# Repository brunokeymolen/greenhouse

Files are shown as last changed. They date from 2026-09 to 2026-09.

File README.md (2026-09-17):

# Greenhouse ESP8266 Relay Controller

Firmware for an ESP-01S relay carrier that ventilates a greenhouse: it reads a
DHT22 and switches a fan - or in winter a lamp or heater - through the on-board
relay.

<p>
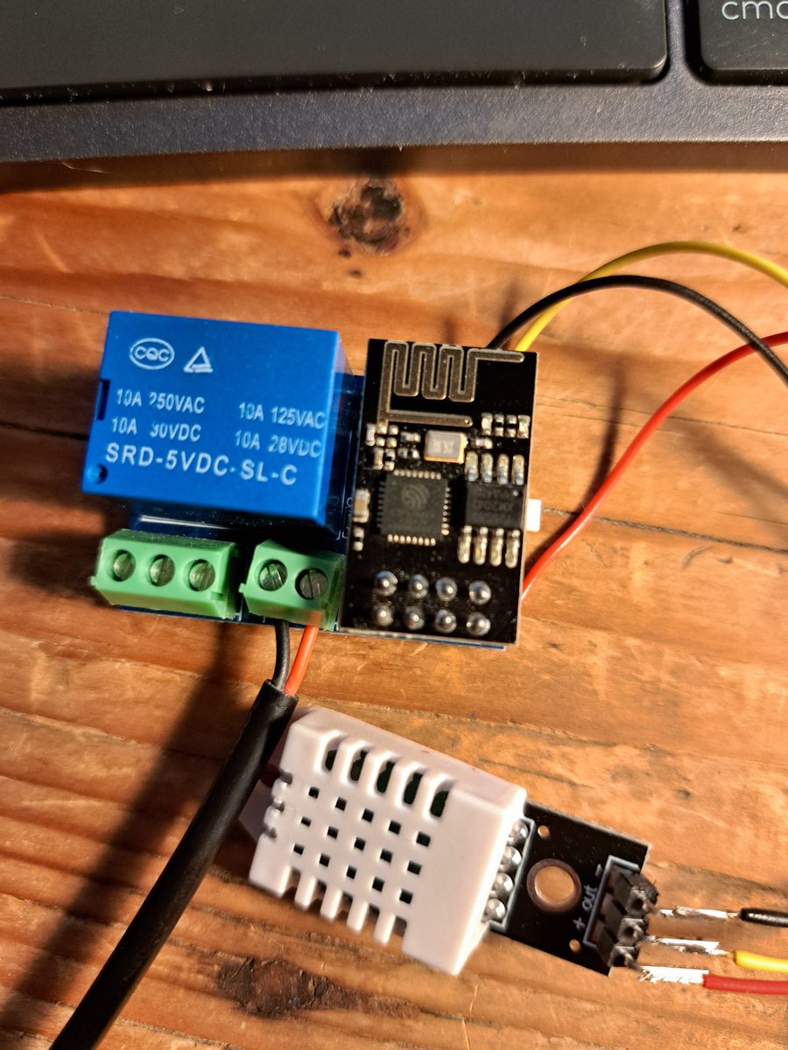
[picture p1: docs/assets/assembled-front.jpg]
ESP-01S module plugged into the relay carrier, with the DHT22 sensor wired to it

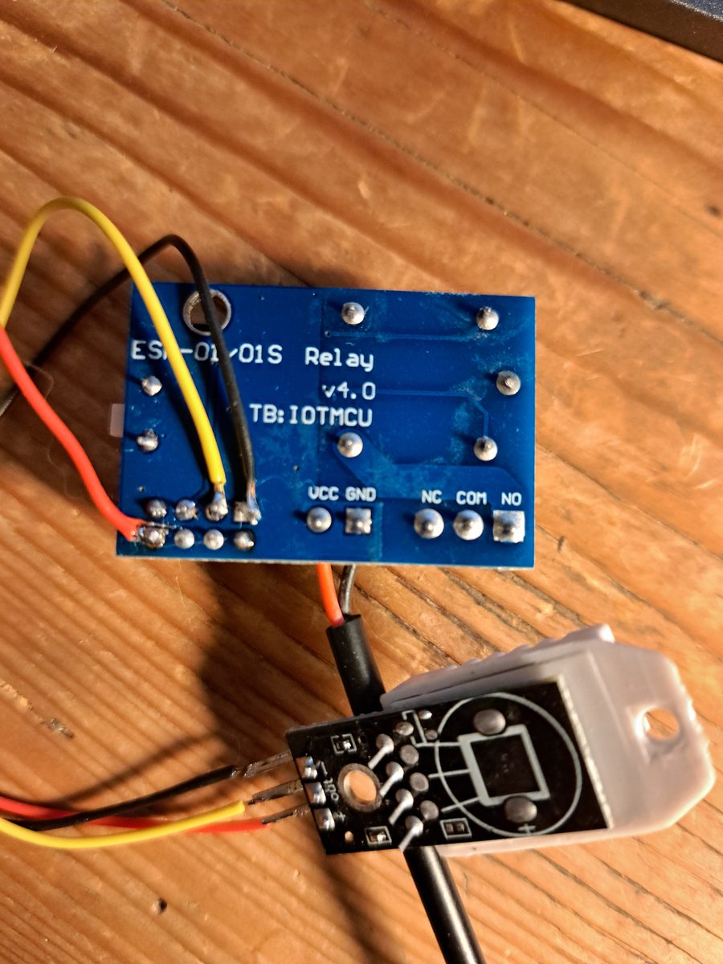
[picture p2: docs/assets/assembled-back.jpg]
Underside of the carrier, showing the ESP-01/01S Relay v4.0 silkscreen and the VCC, GND, NC, COM and NO pads

</p>

**Hardware this is built and tested on**

| Part | What it is |
| --- | --- |
| MCU module | **ESP-01S** - an ESP8266EX with 1 MB flash on the black 8-pin PCB. The build targets 1 MB (`CONFIG_ESPTOOLPY_FLASHSIZE="1MB"`), and the application alone is over 530 kB, so the blue 512 kB ESP-01 will not hold it. |
| Carrier | **ESP-01/01S Relay v4.0**, marked `TB:IOTMCU` on the underside |
| Relay | SRD-05VDC-SL-C, rated 10 A at 250 V AC |
| Sensor | DHT22 / AM2302 (a DHT11 also works; `make menuconfig`) |

Current state: milestones 1-7. The firmware reads a DHT22, runs the fan control
state machine, drives the relay, serves a status and settings page from its own
Wi-Fi access point, and persists its configuration in NVS.

Relay polarity and the GPIO it uses are unconfirmed on real hardware - see
"Bring-up" below before connecting a load.

## Build

Build the toolchain image once, **from the repository root**:

```sh
docker build -t greenhouse-esp8266-idf -f docker/esp8266.Dockerfile .
```

Then build the firmware:

```sh
docker/run.sh make defconfig    # first time only, creates sdkconfig
docker/run.sh make -j
```

`docker/run.sh` mounts this directory into the container, runs as your own user
so build output is not root-owned, sources the SDK environment and passes
`/dev/ttyUSB0` through when it exists.

## Flash and monitor

Put the ESP-01S in the flashing harness, hold `FLASH`, tap `RESET`, then:

```sh
docker/run.sh make -j flash
docker/run.sh make monitor      # exit with Ctrl-]
```

Use `ESPPORT=/dev/ttyUSB1 docker/run.sh ...` for a different serial device. If
opening the port is denied, add yourself to the `dialout` group on the host.

Expected output at 115200 baud:

```text
I (xx) greenhouse: greenhouse controller starting, sdk v3.4
I (xx) sensor: polling DHT22 on GPIO2 every 5 s
I (xx) wifi: SSID Greenhouse-A1B2 up, browse to 192.168.4.1
I (xx) web: http server listening on port 80
I (xx) sensor: 22 C, 47 %RH
```

The ESP8266 ROM bootloader prints its first lines at 74880 baud, so those will
look like garbage in a 115200 terminal. That is normal.

## Using it

Join the `Greenhouse-XXXX` Wi-Fi network (factory password `greenhouse`, change
it with `docker/run.sh make menuconfig`) and open <http://192.168.4.1>. The page
polls `/api/status` every two seconds.

| Path | Method | Purpose |
| --- | --- | --- |
| `/` | GET | Status and settings page |
| `/api/status` | GET | Reading, sensor health, device stats |
| `/api/config` | GET | Current configuration |
| `/api/config` | POST | Validate and save configuration |
| `/api/scan` | GET | Nearby networks, strongest first; blocks ~2 s |
| `/api/history` | GET | Samples for the chart; `?days=1..7` trims the range |
| `/api/relay/test` | POST | Energise the relay briefly; `?seconds=1..5` |
| `/api/reboot` | POST | Restart the controller |

```sh
curl http://192.168.4.1/api/status
```

```json
{"ssid":"Greenhouse-A1B2","valid":true,"stale":false,"temperature_c":22,
 "humidity_pct":47,"age_s":3,"reads_ok":120,"reads_failed":2,
 "last_error":"ok","clients":1,"uptime_s":610,"free_heap":31240}
```

Settings are edited on the page or posted directly. A POST updates only the
fields it names, and is rejected as a whole if any value is out of range — no
partial writes, and out-of-range values are refused rather than silently clamped:

```sh
curl -X POST http://192.168.4.1/api/config \
  -H 'Content-Type: application/json' \
  -d '{"temp_threshold_c":28,"start_delay_s":90}'
```

```json
{"saved":true}
```

| Setting | Default | Bounds |
| --- | ---: | ---: |
| `temp_threshold_c` | 30 | 0-50 |
| `humidity_threshold_pct` | 80 | 20-95 |
| `start_delay_s` | 120 | 0-3600 |
| `max_fan_duration_s` | 900 | 30-7200 |
| `grace_period_s` | 300 | 0-7200 |
| `sensor_poll_interval_s` | 5 | 2-60 |
| `fan_mode` | 1 (auto) | 0 off / 1 auto / 2 on |
| `trigger_direction` | 0 (above) | 0 above / 1 below thresholds |
| `device_name` | `"Fan"` | 1-23 bytes |
| `ap_ssid` | `""` (derive from MAC) | 0-32 bytes |
| `wifi_mode` | 0 (own access point) | 0 access point / 1 join a network |
| `ap_password` | `greenhouse` | 8-63 bytes, or empty for an open network |
| `sta_ssid` | `""` | 0-32 bytes, required when `wifi_mode` is 1 |
| `sta_password` | `""` | 8-63 bytes, or empty for an open network |
| `temp_enabled` | true | bool |
| `humidity_enabled` | true | bool |
| `relay_active_low` | false | bool |

Times are entered in minutes on the page; the API uses seconds throughout.

Both passwords are write-only over the API: `GET /api/config` reports
`ap_password_set` and `sta_password_set` rather than the values, and a `POST`
that carries an empty password leaves the stored one alone.

Settings persist across reboots in NVS. A stored config that is corrupt, written
by a different config version, or out of bounds is discarded and the defaults are
rewritten, so a bad value can never reach the controller. A config written by
version 1 or 3 of the layout is migrated in place instead, keeping the settings
it did have.

Occasional entries in `reads_failed` are normal for a DHT sensor. A rising
`reads_failed` with `valid:false` means wiring — check the pull-up first.

### Power supply

Power the board from a real 5 V supply, not from a computer's USB port and not
from the 5 V of a USB-serial adapter. An ESP8266 draws ~300 mA peaks while
transmitting; a serial adapter's rail sags under that and starves the 3.3 V
regulator into dropout.

It does not fail in any way that looks like a power problem. It shows up as
humidity readings alternating between the true value and roughly double it, while
temperature looks fine. Worse supply adds temperature excursions, then read
timeouts, then all-zero frames.

Fit the decoupling capacitors as well - 10 uF at the regulator output for loop
stability, and 220-470 uF plus 100 nF at the ESP-01's own VCC/GND pins. Both were
necessary; neither was sufficient.

## Sensor

A DHT22/AM2302 is fitted by default; select `DHT11` in `menuconfig` if that is
what is connected. Both use the same single wire and the same driver - they
differ in the host start pulse (about 1 ms versus 18 ms) and in how the 40
payload bits are encoded.

The DHT22 is the better part for this application, mostly for range rather than
accuracy: the DHT11 is rated 20-90 %RH and 0-50 C, and a greenhouse crosses both
bounds, 90 %RH being exactly the condition that should trigger ventilation.

| | DHT11 | DHT22 |
| --- | --- | --- |
| Humidity | 20-90 %RH, +/-5%, 1% steps | 0-100 %RH, +/-2%, 0.1% steps |
| Temperature | 0-50 C, +/-2 C, 1 C steps | -40 to +80 C, +/-0.5 C, 0.1 C steps |
| Minimum read interval | 1 s | 2 s |

Readings are carried in tenths throughout the firmware, so the DHT22's
resolution reaches the chart and the API; a DHT11 simply reports multiples of
10. Values outside the fitted part's rated range are shown but logged as
unreliable.

## Wiring the sensor

```text
Sensor VCC  -> ESP-01 3V3
Sensor DATA -> ESP-01 GPIO2 (pin 3)
Sensor GND  -> ESP-01 GND
4.7k-10k   -> between DATA and 3V3   (required, the internal pull-up is too weak)
```

GPIO2 is the only free GPIO on the ESP-01 header once the relay takes GPIO0, and
it must be high at boot — which a DHT sensor with its pull-up already is. Change the
pin with `CONFIG_GREENHOUSE_SENSOR_GPIO` if your carrier wires the relay to GPIO2
instead.

## Layout

| Path | Purpose |
| --- | --- |
| `Makefile` | Project makefile for the ESP8266_RTOS_SDK make build system. |
| `main/main.c` | Application entry point. |
| `main/dht.c` | Bit-banged DHT11 / DHT22 driver. |
| `main/sensor.c` | Polling task and the shared reading it publishes. |
| `main/config.c` | NVS-backed runtime configuration with validation. |
| `main/history.c` | In-RAM ring buffer of downsampled samples for the chart. |
| `main/relay.c` | Relay output, runtime polarity, guarded test pulse. |
| `main/controller.c` | Fan control state machine. |
| `main/wifi_ap.c` | SoftAP bring-up. |
| `main/web.c` | Status and settings page, `/api/status`, `/api/config`. |
| `main/Kconfig.projbuild` | `menuconfig` options for pin, timings and AP. |
| `sdkconfig.defaults` | Flash size/mode defaults for ESP-01S. |
| `docker/esp8266.Dockerfile` | Pinned ESP8266_RTOS_SDK v3.4 toolchain image. |
| `docker/run.sh` | Runs a command inside that image against this project. |

## Bring-up

Two things about the relay carrier are unconfirmed, and both must be settled
before mains wiring goes anywhere near it. Do this with no load connected.

The bring-up controls live behind the collapsed **Bring-up tools** section at the
bottom of the page.

1. **Which GPIO drives the relay.** The firmware assumes GPIO0
   (`CONFIG_GREENHOUSE_RELAY_GPIO`). A minority of carriers use GPIO2, which
   would collide with the sensor. Check with a continuity meter, unpowered,
   between the relay driver input and socket pins 3 (GPIO2) and 5 (GPIO0).
2. **Active-high or active-low.** Press *Test relay* on the web page and listen
   for the click. If the relay is energised when the fan should be off, press
   *Invert polarity*. This is a runtime setting stored in NVS, so no reflash is
   needed to try both.

The test pulse is capped at 5 seconds in firmware and turns itself off with a
timer armed after the relay switches on, so a lost connection or a crashed
browser cannot leave the relay latched.

Note the relay may click once at power-up: GPIO0 is the boot strap and is held
high by its pull-up until `relay_init()` runs. On an active-high carrier that
means a brief energised window. `relay_init()` is the first thing `app_main()`
does after loading config, to keep it short.

## Fan control

```text
IDLE           conditions normal, fan off
WAITING        over threshold, waiting out start_delay
FAN_ON         fan running
GRACE          conditions normal again, fan still running for grace_period
GRACE_FORCED   max_fan_duration hit; fan off and locked out for grace_period
FAULT          no usable reading for 60 s; fan off
```

## Network settings

The device either serves its own access point or joins an existing network. The
choice, both network names and both passwords live behind the collapsed
**Network settings** section near the bottom of the page, next to **Bring-up
tools**, with its own save button - none of it is part of the everyday settings
form.

**Own access point** is the factory state and needs no other equipment. Leave
the name empty and the device derives `Greenhouse-XXXX` from the last two bytes
of its own MAC, so several units stay distinguishable without configuring each
one.

**Join a network** puts the readings on your house network, reachable from
anywhere in it rather than only from within radio range of the greenhouse. The
device registers the access point name as its DHCP hostname, so it can be found
in the router's client list without hunting for an address.

**Scan for networks** lists what is in range with a signal strength for each, so
the name can be picked rather than typed. It takes a couple of seconds: serving
its own access point the device has no station interface, so it adds one for the
duration, and the sweep across the channels stalls the page until it finishes.
Duplicate names - repeaters, mesh nodes - are collapsed to their strongest
sighting. A hidden network, or one whose name is not valid text, is not listed
but can still be joined by typing the name into the field below the list.

A change applies **on restart**, not immediately: reconfiguring the radio while
serving the request that asked for it would drop the reply, and the page could
not then tell success from failure. Save, then use *Restart device* under
*Bring-up tools*, then reconnect.

Passwords are never sent back to the browser - the page is told only whether one
is set. An empty password field therefore means *leave it unchanged*, not *clear
it*, so a form submitted without retyping the password cannot open the network by
accident.

### When it cannot join

If the configured network cannot be joined at startup, the device raises a
**recovery access point** instead and says so in a banner at the top of the page.

Nothing is written when that happens. The stored setting still says "join that
network", so the next restart tries it again, and if nobody connects to the
recovery access point within ten minutes the device restarts by itself to do
exactly that. A router that was merely slow to come back, or briefly rebooted,
therefore heals without anyone walking out to the greenhouse.

Once the network has been joined successfully, a later disconnection does *not*
drop to recovery: the device reconnects indefinitely, so a router reboot never
costs you the connection. Only if it stays unreachable for fifteen minutes does
it restart and re-run the join attempts.

The recovery access point uses the **configured** AP password, not the factory
one. Otherwise anyone able to knock the house router offline would be handed a
network with a documented default password and a relay on the other end.
Recovery is for "my router changed", not for "I forgot my password" - that is
what the factory reset below is for.

## Factory reset

Tap the reset button on the board **five times in a row**, roughly a second
apart. The relay clicks three times to confirm, and the device comes back on its
own access point with the built-in password (`CONFIG_GREENHOUSE_AP_PASSWORD`,
`greenhouse` unless you changed it at build time). Every other setting returns to
its default too.

The page also says so in a banner for the first fifteen minutes after the reset.
That is a one-time notice rather than a state: once there has been time to see
it, it clears itself, so a working device is not left showing a warning until its
next restart.

This is the only way back into a device whose password has been forgotten or
whose network no longer exists, and it deliberately requires physical access.
There is nothing to reflash.

It has to be the reset button because there is nothing else: GPIO0 drives the
relay, GPIO2 the sensor, GPIO1 and GPIO3 are the UART, and the ESP-01 header
breaks out nothing more. And it has to be *taps* rather than a long press,
because RST is an asynchronous hardware reset - while it is held the CPU is in
reset and no code is running to time it. Holding the button for ten seconds is
indistinguishable from tapping it once.

What is observable is how each boot was caused. A tap reports `ESP_RST_EXT` and
finds the previous boot's count still in RTC memory, which survives a reset but
not a power cut; five in quick succession is a deliberate act. A crash reports
`ESP_RST_PANIC` and a hang `ESP_RST_WDT`, either of which breaks the chain - so a
device stuck in a boot loop keeps its configuration instead of quietly wiping it.
Waiting more than five seconds between taps also ends the chain, which is what
stops unrelated resets over a whole season from ever adding up.

The count, the window and the confirmation clicks are all configurable under
*Greenhouse controller* in `make menuconfig`.

## Naming the load

The relay does not have to switch a fan. `device_name` sets what the page calls
it - "Cooling", "Water pump", "Lamp", "Heater" - and the label follows through
the status line, the chart legend, the trigger settings and every message. It is
cosmetic; no behaviour depends on it.

The field is under **Controlled device** near the bottom of the page, with its
own save button, since it is set once at installation rather than adjusted from
day to day.

Quotes, backslashes and control characters are refused so the value needs no
escaping when it goes into JSON, and the page always renders it with
`textContent`, so markup inside a name is inert rather than interpreted. UTF-8 is
allowed.

## Fan mode

A three-way switch at the top of the page: **Off / Auto / On**.

Off and On are operator overrides that ignore the readings entirely. They are
stored in flash and survive a reboot, and the page shows a standing warning while
either is active, because a fan that cannot respond to conditions should never
look like normal operation.

Forced on has **no time limit**. `max_fan_duration_s` bounds automatic control
against a stuck sensor; it is not meant to overrule a deliberate choice, so a
forced-on fan runs until someone sets the mode back to Auto.

Returning to Auto restarts the state machine from idle rather than resuming the
timers that were frozen while forced.

## Fan triggers

Either input can be taken out of the decision with `temp_enabled` /
`humidity_enabled` while still being measured, logged and charted. A disabled
input never triggers. With both disabled the relay cannot switch on
automatically; that is permitted but reported in the status so it is not
mistaken for a fault.

### Above or below

`trigger_direction` picks which side of the thresholds switches the load on. It
applies to both inputs at once - one relay serves one purpose, and mixing
directions would mean a load asked to run both when it is too cold and when it is
too damp.

**Above thresholds** (the default) is ventilation: the relay switches on when
temperature or humidity is at or above its threshold. Hot but dry still needs
air, and so does cool but damp.

**Below thresholds** inverts it, for winter: a lamp or a heater that runs while
temperature or humidity is at or below its threshold. The boundary belongs to
both directions, so a reading exactly at the threshold counts as triggered
either way.

Nothing downstream changes. The start delay, the bounded run and the grace
period behave identically; only the comparison flips. `max_fan_duration_s` still
bounds a single run, which matters just as much for a heater with a stuck sensor
as for a fan.

The selector is under **Trigger direction** near the bottom of the page and
applies immediately - there is no restart and no save button.

## Configuration

```sh
docker/run.sh make menuconfig    # Greenhouse controller
```

| Option | Default |
| --- | --- |
| `GREENHOUSE_SENSOR_TYPE` | DHT22 |
| `GREENHOUSE_SENSOR_GPIO` | 2 |
| `GREENHOUSE_SENSOR_POLL_INTERVAL_S` | 5 (initial default only; runtime value lives in NVS) |
| `GREENHOUSE_SENSOR_STALE_TIMEOUT_S` | 60 |
| `GREENHOUSE_AP_PASSWORD` | `greenhouse` (factory value; runtime value lives in NVS) |
| `GREENHOUSE_AP_CHANNEL` | 1 |
| `GREENHOUSE_AP_MAX_CONN` | 4 |
| `GREENHOUSE_STA_CONNECT_ATTEMPTS` | 10 |
| `GREENHOUSE_RECOVERY_AP_IDLE_S` | 600 |
| `GREENHOUSE_STA_DOWN_RESTART_S` | 900 |
| `GREENHOUSE_FACTORY_RESET_PRESSES` | 5 |
| `GREENHOUSE_FACTORY_RESET_WINDOW_S` | 5 |
| `GREENHOUSE_FACTORY_RESET_CLICK` | y |
| `GREENHOUSE_HISTORY_SAMPLES` | 2016 (7 days, ~6 kB) |
| `GREENHOUSE_HISTORY_INTERVAL_S` | 300 |

## History chart

The page charts 1 to 7 days, selectable above the chart, as two stacked panels
sharing one x-axis:
temperature and humidity, with orange bands marking when the fan ran and grey
bands where no valid reading was taken.

Two panels rather than one chart with two y-axes, deliberately. A dual-axis chart
lets the author place two unrelated scales so the lines appear to correlate, and
the reader has no way to tell that apart from a real relationship.

The range is applied on the device, not in the browser. Seven days is about
12 kB of JSON and the page refetches every minute; a one-day view is nearer
1.7 kB, which is worth having on a part with 62 kB of free heap.

Sensor polls are averaged into 5-minute buckets. A bucket with no valid reading
is stored as a gap and drawn as one - never as a zero, which would read as
"cold and dry" and is exactly the misreading a fan controller must not make.

History is RAM-only and is lost on reboot. Persisting it would mean a flash write
every 5 minutes, which wears the part out on a device meant to run for seasons.
2016 samples cost about 6 kB of static RAM.

## License

MIT - see [LICENSE](LICENSE). Source files carry an SPDX identifier rather than
the full text.

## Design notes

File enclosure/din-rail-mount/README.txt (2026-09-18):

DIN Rail mount for ESP 01S incl. Relay module by NobodysNightmare on Thingiverse: https://www.thingiverse.com/thing:4821541

Summary:
This is a DIN Rail mount for an ESP 01(S) including the standard relay module for it.Depending on how the print comes out, this will either tightly fit or the module can slide out itself. However, you will always be able to align it on the right side, so once mounted even a loose fit should not be a problem.Supports from the print bed are required.

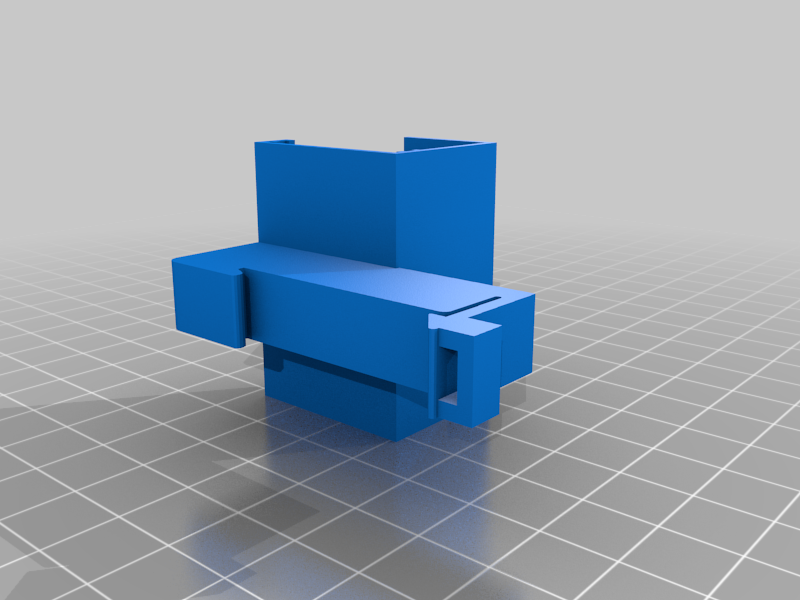
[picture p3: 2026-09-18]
enclosure/din-rail-mount/images/doorbell-clip.png

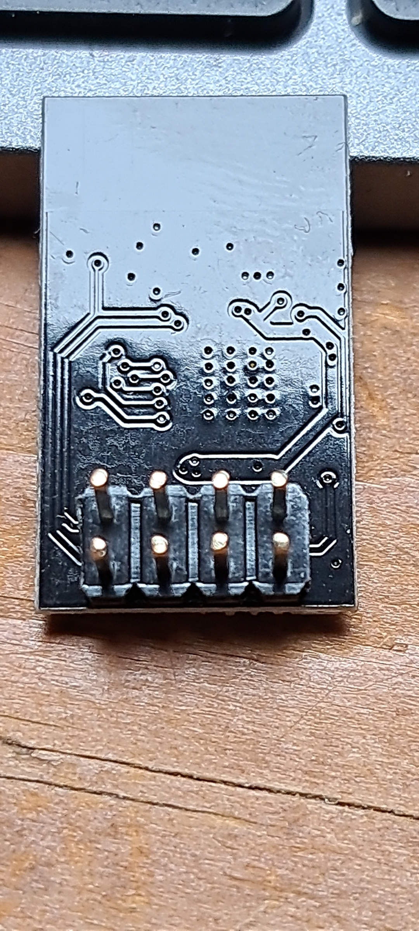
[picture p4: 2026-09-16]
docs/assets/esp8266-esp01-back.jpg

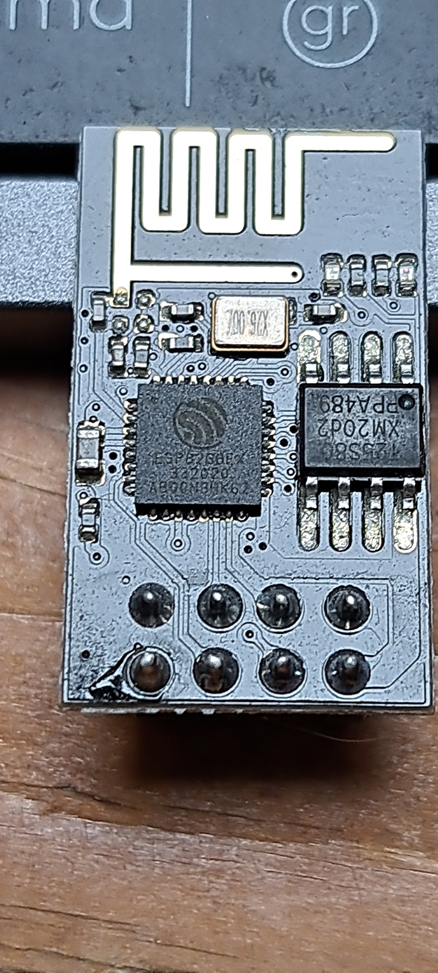
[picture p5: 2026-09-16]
docs/assets/esp8266-esp01-front.jpg

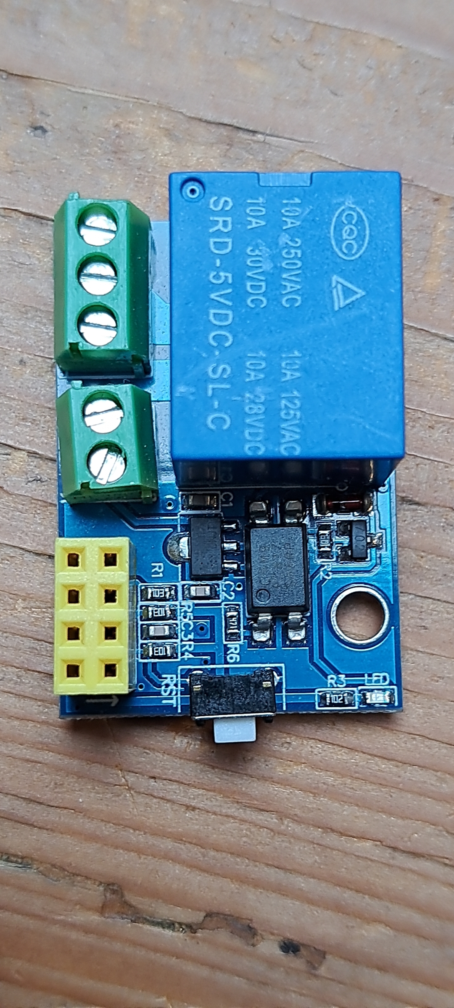
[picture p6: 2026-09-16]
docs/assets/relay-board.jpg

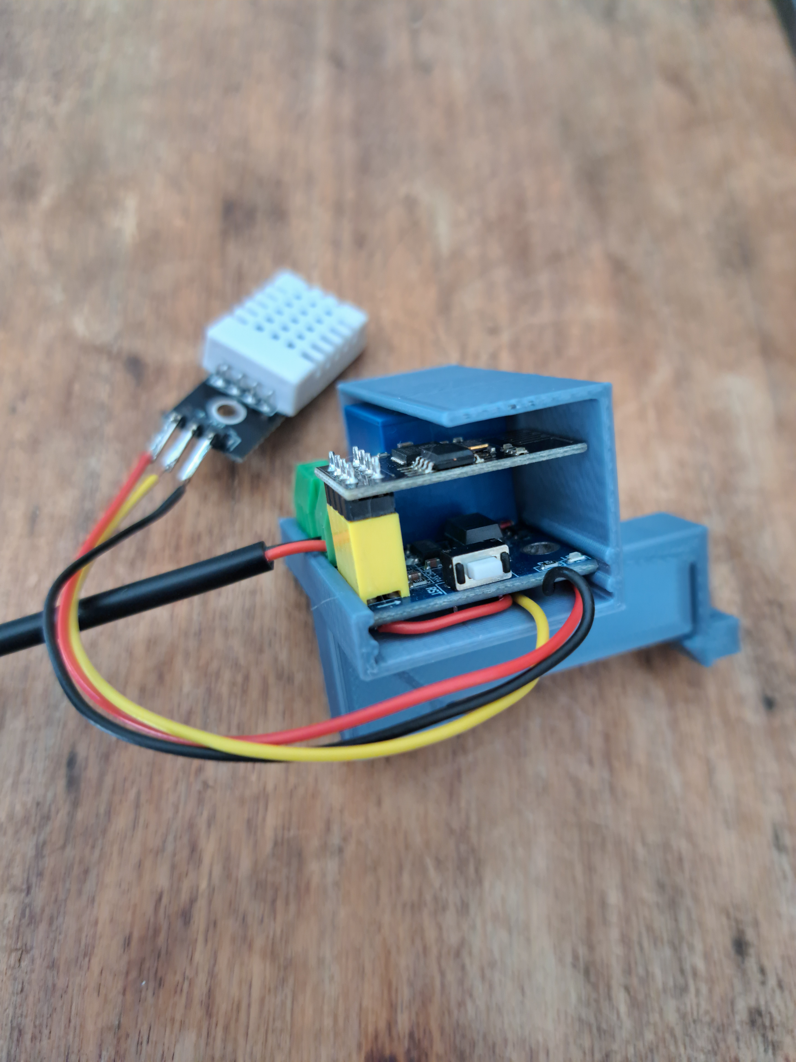
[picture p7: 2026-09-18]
enclosure/enclosure1.jpg

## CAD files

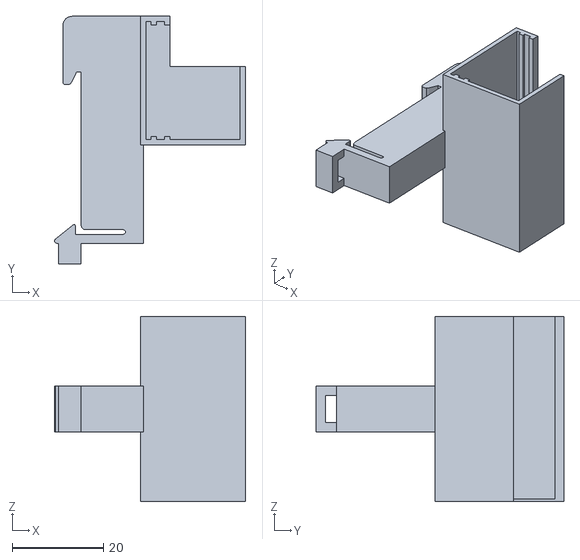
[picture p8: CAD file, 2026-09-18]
enclosure/din-rail-mount/files/doorbell-clip.stl
41.8 x 54.2 x 40.6

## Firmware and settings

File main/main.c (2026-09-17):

/*
 * Copyright (c) 2026 Bruno Keymolen
 * SPDX-License-Identifier: MIT
 */

/*
 * Greenhouse ESP8266 relay controller.
 *
 * Milestones 1-3: boots, polls the sensor, and serves a status page from its own
 * access point. The relay is not driven yet; see docs/DESIGN.md.
 *
 * Serial note: with CONFIG_GREENHOUSE_SENSOR_GPIO set to 2 the UART console stays
 * usable. If the sensor is moved to GPIO1/TX, serial logging and the sensor
 * share a pin and the web UI becomes the only usable console.
 */

#include "esp_log.h"
#include "esp_system.h"
#include "freertos/FreeRTOS.h"
#include "freertos/task.h"
#include "config.h"
#include "controller.h"
#include "factory_reset.h"
#include "history.h"
#include "relay.h"
#include "nvs_flash.h"
#include "sdkconfig.h"
#include "sensor.h"
#include "wifi.h"
#include "web.h"

static const char *TAG = "greenhouse";

void app_main(void)
{
    ESP_LOGI(TAG, "greenhouse controller starting, sdk %s", esp_get_idf_version());

    /* The Wi-Fi driver keeps calibration data in NVS. A partition left over from
     * an older layout is recoverable by erasing it rather than failing to boot. */
    esp_err_t err = nvs_flash_init();
    if (err == ESP_ERR_NVS_NO_FREE_PAGES) {
        ESP_LOGW(TAG, "nvs has no free pages, erasing");
        ESP_ERROR_CHECK(nvs_flash_erase());
        err = nvs_flash_init();
    }
    ESP_ERROR_CHECK(err);

    /* Config must load before the sensor task reads its poll interval. */
    err = config_load();
    if (err != ESP_OK) {
        ESP_LOGE(TAG, "config_load failed: %s, continuing on defaults",
                 esp_err_to_name(err));
    }

    /*
     * Relay first, before Wi-Fi and the web server. GPIO0 is the boot strap and
     * sits high until we drive it, so on an active-high carrier the relay is
     * energised until this call. Every millisecond before it is fan-on time.
     */
    err = relay_init();
    if (err != ESP_OK) {
        ESP_LOGE(TAG, "relay_init failed: %s", esp_err_to_name(err));
    }

    /*
     * After config_load(), which creates the configuration this may overwrite,
     * and after relay_init(), so the relay is already in its off state before
     * any confirmation clicks. Before Wi-Fi, so a reset takes effect on the
     * network the device brings up rather than the next boot's.
     */
    factory_reset_check();

    err = history_init();
    if (err != ESP_OK) {
        ESP_LOGE(TAG, "history_init failed: %s", esp_err_to_name(err));
    }

    /* Start the sensor first so the UI has something to show immediately. */
    err = sensor_start();
    if (err != ESP_OK) {
        ESP_LOGE(TAG, "sensor_start failed: %s", esp_err_to_name(err));
    }

#if CONFIG_GREENHOUSE_DIAG_NO_WIFI
    ESP_LOGW(TAG, "diagnostic build: Wi-Fi and web server disabled");
#else
    ESP_ERROR_CHECK(wifi_start());
    ESP_ERROR_CHECK(web_start());
#endif

    err = controller_start();
    if (err != ESP_OK) {
        ESP_LOGE(TAG, "controller_start failed: %s", esp_err_to_name(err));
    }

    ESP_LOGI(TAG, "ready, free heap %u bytes", esp_get_free_heap_size());

    while (1) {
        vTaskDelay(pdMS_TO_TICKS(30000));
        ESP_LOGI(TAG, "free heap %u bytes", esp_get_free_heap_size());
    }
}

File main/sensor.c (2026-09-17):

/*
 * Copyright (c) 2026 Bruno Keymolen
 * SPDX-License-Identifier: MIT
 */

#include "sensor.h"

#include <string.h>

#include <stdio.h>
#include <stdlib.h>

#include "config.h"
#include "dht.h"
#include "history.h"
#include "esp_log.h"
#include "esp_timer.h"
#include "freertos/FreeRTOS.h"
#include "freertos/semphr.h"
#include "freertos/task.h"
#include "sdkconfig.h"

/*
 * A single bad frame is normal on a DHT11, so retry a few times inside one poll
 * before recording a failure.
 */
#define SENSOR_READ_ATTEMPTS 3

static const char *TAG = "sensor";

static SemaphoreHandle_t s_lock;

static struct {
    bool valid;
    int16_t temperature_dc;
    int16_t humidity_dpct;
    int64_t last_ok_us;
    uint32_t reads_ok;
    uint32_t reads_failed;
    esp_err_t last_error;
} s_state;

const char *sensor_model(void)
{
    return dht_model();
}

const char *sensor_error_name(esp_err_t err)
{
    switch (err) {
    case ESP_OK:
        return "ok";
    case ESP_ERR_TIMEOUT:
        return "timeout";
    case ESP_ERR_INVALID_CRC:
        return "checksum";
    case ESP_ERR_INVALID_RESPONSE:
        return "empty frame";
    case ESP_ERR_INVALID_STATE:
        return "not initialised";
    default:
        return "error";
    }
}

void sensor_get(sensor_snapshot_t *out)
{
    if (out == NULL) {
        return;
    }

    memset(out, 0, sizeof(*out));

    if (s_lock == NULL) {
        out->last_error = ESP_ERR_INVALID_STATE;
        return;
    }

    xSemaphoreTake(s_lock, portMAX_DELAY);

    out->valid = s_state.valid;
    out->temperature_dc = s_state.temperature_dc;
    out->humidity_dpct = s_state.humidity_dpct;
    out->reads_ok = s_state.reads_ok;
    out->reads_failed = s_state.reads_failed;
    out->last_error = s_state.last_error;

    if (s_state.valid) {
        int64_t age_us = esp_timer_get_time() - s_state.last_ok_us;
        out->age_s = (uint32_t)(age_us / 1000000);
        out->stale = out->age_s >= CONFIG_GREENHOUSE_SENSOR_STALE_TIMEOUT_S;
    } else {
        out->stale = true;
    }

    xSemaphoreGive(s_lock);
}

/*
 * Dump the raw frame and the pulse width of every bit. A decode problem shows up
 * as pulse widths clustered near the 45 us threshold; a genuinely noisy sensor
 * shows clean widths with changing data.
 */
static void sensor_log_frame(void)
{
    uint8_t bytes[5];
    int pulse_us[40];
    dht_last_frame(bytes, pulse_us);

    ESP_LOGI(TAG, "raw %02x %02x %02x %02x %02x (sum %02x)",
             bytes[0], bytes[1], bytes[2], bytes[3], bytes[4],
             (uint8_t)(bytes[0] + bytes[1] + bytes[2] + bytes[3]));

    char line[8 * 5 + 1];
    for (int b = 0; b < 5; b++) {
        int n = 0;
        for (int i = 0; i < 8; i++) {
            n += snprintf(line + n, sizeof(line) - n, "%d ", pulse_us[b * 8 + i]);
        }
        ESP_LOGI(TAG, "  byte%d us: %s", b, line);
    }
}

static void sensor_task(void *arg)
{
    /* The DHT11 needs about a second after power-up before its first
     * conversion is meaningful. */
    vTaskDelay(pdMS_TO_TICKS(2000));

    while (1) {
        /* Re-read each cycle so a change from the web UI applies without a
         * reboot, from the next reading onwards. */
        greenhouse_config_t cfg;
        config_get(&cfg);
        const TickType_t period = pdMS_TO_TICKS(cfg.sensor_poll_interval_s * 1000);

        /* Zeroed because it is passed to history_add() even on failure,
         * where the values are ignored but must still be initialised. */
        dht_reading_t reading = {0};
        esp_err_t err = ESP_FAIL;

        for (int attempt = 0; attempt < SENSOR_READ_ATTEMPTS; attempt++) {
            err = dht_read(&reading);
            if (err == ESP_OK) {
                break;
            }
        }

        xSemaphoreTake(s_lock, portMAX_DELAY);

        s_state.last_error = err;

        if (err == ESP_OK) {
            s_state.valid = true;
            s_state.temperature_dc = reading.temperature_dc;
            s_state.humidity_dpct = reading.humidity_dpct;
            s_state.last_ok_us = esp_timer_get_time();
            s_state.reads_ok++;
        } else {
            s_state.reads_failed++;
        }

        xSemaphoreGive(s_lock);

        history_add(err == ESP_OK, reading.temperature_dc, reading.humidity_dpct);

        if (err == ESP_OK) {
            ESP_LOGI(TAG, "%d.%d C, %d.%d %%RH",
                     reading.temperature_dc / 10, abs(reading.temperature_dc % 10),
                     reading.humidity_dpct / 10, abs(reading.humidity_dpct % 10));

            /* Outside the part's rated range the value is reported but should
             * not be trusted. A greenhouse really can sit outside it. */
            if (reading.humidity_dpct < dht_humidity_min_dpct() ||
                reading.humidity_dpct > dht_humidity_max_dpct()) {
                ESP_LOGW(TAG, "humidity %d.%d %%RH is outside the %s's rated "
                              "%d-%d %%RH range, treat as unreliable",
                         reading.humidity_dpct / 10, abs(reading.humidity_dpct % 10),
                         dht_model(),
                         dht_humidity_min_dpct() / 10, dht_humidity_max_dpct() / 10);
            }
            if (reading.temperature_dc < dht_temperature_min_dc() ||
                reading.temperature_dc > dht_temperature_max_dc()) {
                ESP_LOGW(TAG, "temperature %d.%d C is outside the %s's rated "
                              "%d-%d C range, treat as unreliable",
                         reading.temperature_dc / 10, abs(reading.temperature_dc % 10),
                         dht_model(),
                         dht_temperature_min_dc() / 10, dht_temperature_max_dc() / 10);
            }

            sensor_log_frame();
        } else {
            ESP_LOGW(TAG, "read failed after %d attempts: %s",
                     SENSOR_READ_ATTEMPTS, sensor_error_name(err));
        }

        vTaskDelay(period);
    }
}

esp_err_t sensor_start(void)
{
    s_lock = xSemaphoreCreateMutex();
    if (s_lock == NULL) {
        return ESP_ERR_NO_MEM;
    }

    esp_err_t err = dht_init(CONFIG_GREENHOUSE_SENSOR_GPIO);
    if (err != ESP_OK) {
        ESP_LOGE(TAG, "dht_init on GPIO%d failed: %s",
                 CONFIG_GREENHOUSE_SENSOR_GPIO, esp_err_to_name(err));
        return err;
    }

    s_state.last_error = ESP_ERR_INVALID_STATE;

    if (xTaskCreate(sensor_task, "sensor", 2048, NULL, 5, NULL) != pdPASS) {
        return ESP_ERR_NO_MEM;
    }

    greenhouse_config_t cfg;
    config_get(&cfg);
    ESP_LOGI(TAG, "polling %s on GPIO%d every %d s",
             dht_model(), CONFIG_GREENHOUSE_SENSOR_GPIO, cfg.sensor_poll_interval_s);

    return ESP_OK;
}

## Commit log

2026-09-16 Initial commit: greenhouse ESP8266 relay controller
    ESP8266_RTOS_SDK (v3.4) firmware for a greenhouse relay controller:
    DHT sensor sampling, relay control with scheduling/thresholds, a web
    UI, Wi-Fi AP provisioning, and history tracking. Includes a Docker
    based toolchain and design docs.
2026-09-17 config: add runtime Wi-Fi settings, layout version 4
    Move the Wi-Fi configuration out of Kconfig and into NVS: a mode
    (own access point or join an existing network), both network names
    and both passwords. CONFIG_GREENHOUSE_AP_PASSWORD becomes the factory
    default rather than the only value.
    Passphrases are validated as 8 to 63 printable characters. An empty
    one is allowed and means an open network, but a length of 1 to 7 is
    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
2026-09-17 wifi: selectable station mode, recovery AP, and a factory reset
    The device can now join an existing network instead of only serving
    its own. wifi_ap.c becomes wifi.c, since it no longer only does AP.
    If the configured network cannot be joined at boot, a recovery access
    point comes up for that boot alone. Nothing is persisted, so the next
    restart tries the network again, and the device restarts by itself
    after ten idle minutes to do exactly that -- a router that was merely
    slow to come back heals unattended. Once associated, later drops just
    reconnect rather than demoting a working device; only fifteen minutes
    of silence triggers a restart. The recovery AP uses the configured
    password, not t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
    [main.c]
2026-09-17 controller: add a below-thresholds trigger direction
    Until now the relay switched on when a reading was at or above its
    threshold, which only describes ventilation. `trigger_direction`
    inverts the comparison so the same machine drives a lamp or a heater
    holding a winter minimum.
    It applies to both inputs at once. One relay serves one purpose, and
    mixing directions across inputs would mean a load asked to run both
    when it is too cold and when it is too damp.
    Only the comparison changes. The start delay, the bounded run and the
    grace period are identical either way, and max_fan_duration bounds a
    single run just as usefully for a heater with a stuck sensor as for a
    fan. A reading exactly at a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
2026-09-17 web: scan for networks instead of typing the name
    Joining a network meant knowing its name exactly and typing it into a
    field that gives no feedback until the next reboot. /api/scan now
    returns what is in range, strongest first, and the station section
    lists it with a signal bar per entry; picking one fills the name field,
    which stays editable for hidden networks.
    Serving only an access point there is no station interface to scan
    with, so wifi_scan() adds one for the duration and removes it again
    rather than leaving the device in APSTA answering as a station it is
    not using. The sweep stalls the radio for roughly two seconds, so the
    page stops polling status while it runs instead of queuein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
2026-09-17 factory_reset: stop announcing the reset after fifteen minutes
    factory_reset_triggered() was set once at boot and never cleared, so
    /api/status kept reporting it and the page kept drawing the red banner
    for the whole uptime. Only a restart cleared it.
    The recovery-AP banner beside it describes an ongoing state worth
    showing indefinitely; this one is a one-time notice. Once there has
    been time to see it, a warning sitting on a device that is working
    normally is just noise. Time from boot doubles as the age of the
    notice, since the reset happened during this boot, so no extra state
    is needed and it clears itself whether or not anyone opened the page.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
2026-09-17 docs: photos of the assembled unit, and name the exact hardware
    The README described "an ESP-01S relay carrier" and said it was
    "tested with the ESP8266EX", which names the SoC rather than the
    module and does not tell anyone what to buy. Name the parts instead:
    the ESP-01S module, the ESP-01/01S Relay v4.0 carrier marked
    TB:IOTMCU, the SRD-05VDC-SL-C relay, and the DHT22.
    The flash size matters enough to spell out. The build targets 1 MB and
    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
2026-09-17 Add MIT license, and drop the design document from the README
    Every .c and .h in main/ gains a two-line SPDX header rather than the
    full licence text, which would be twenty lines repeated nineteen times.
    LICENSE at the root carries the text itself.
    The README no longer points at docs/DESIGN.md. Where the reference was
    the whole sentence it goes with it; where it only qualified an
    instruction, the instruction stays. The document itself is untouched.
    [dht.c]
